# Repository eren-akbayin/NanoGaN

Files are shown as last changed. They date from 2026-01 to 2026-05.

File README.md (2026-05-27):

# NanoGaN

GaN-based motor driver using Infineon's latest GaN switches. Supports up to 60V (depending on GaN device selection).

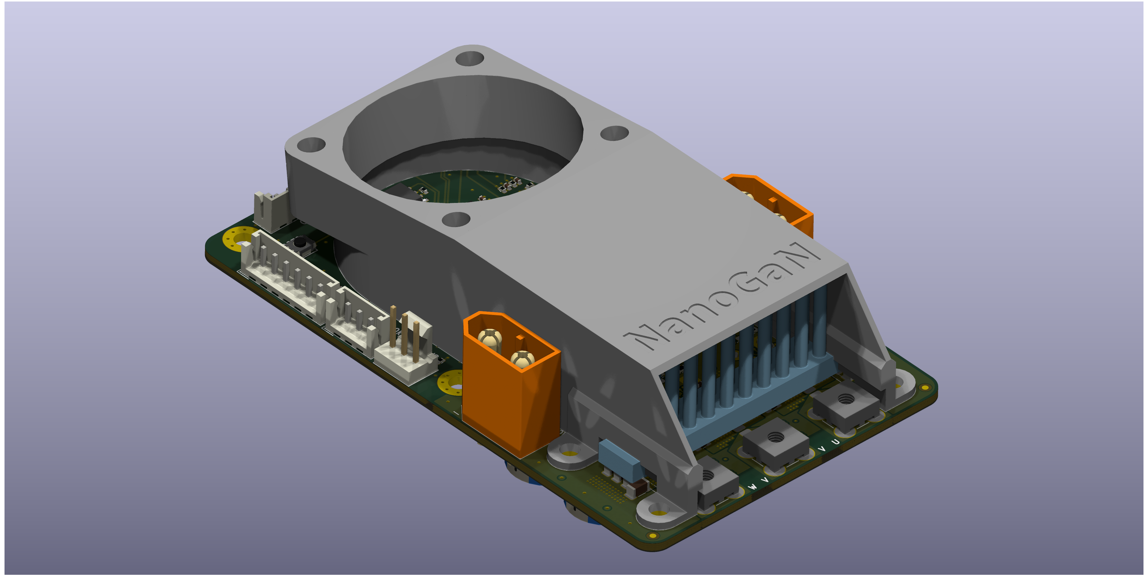
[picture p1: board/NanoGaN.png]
NanoGaN Board

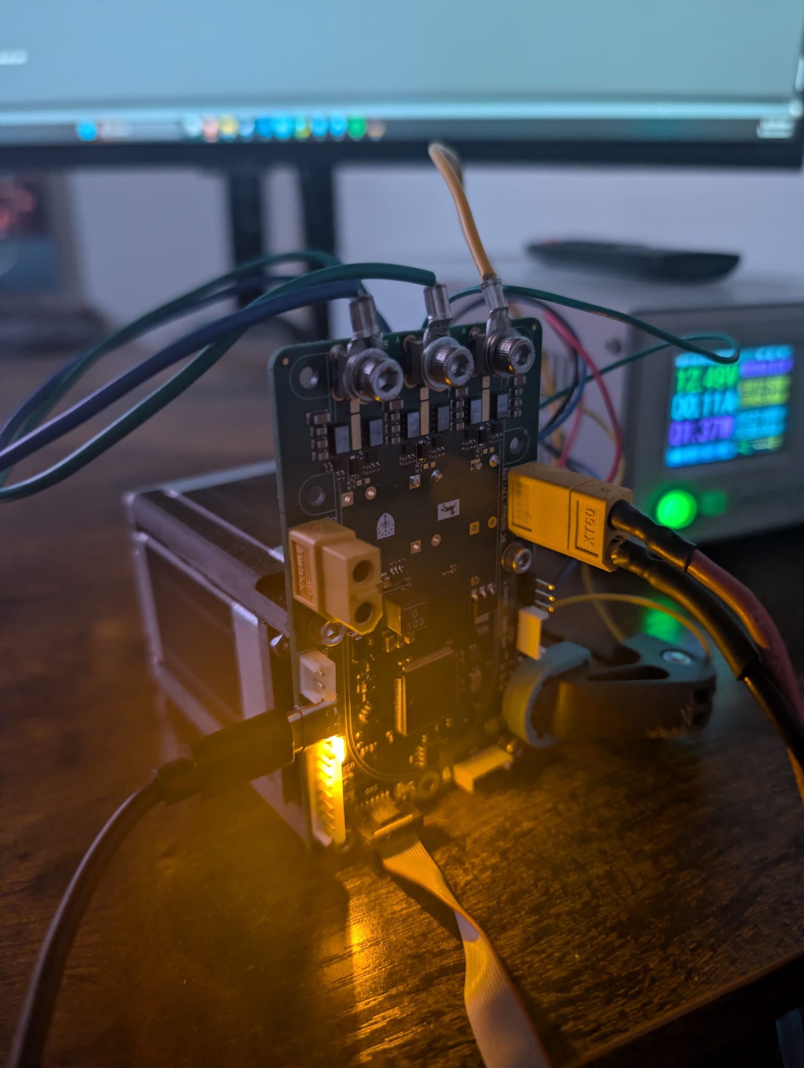
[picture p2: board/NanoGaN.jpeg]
NanoGaN Board


## Project Structure

- `NanoGaN.kicad_sch` - Main schematic file
- `NanoGaN.kicad_pcb` - PCB layout
- `half_bridge.kicad_sch` - Half bridge circuit schematic
- `power.kicad_sch` - Power supply schematic
- `mcu.kicad_sch` - Microcontroller schematic
- `connectors.kicad_sch` - Connector schematic

## Folders

- `board/` - 3D board render and PDF schematic
- `NanoGaN_3D_models/` - Component 3D models
- `NanoGaN.pretty/` - Custom footprints and symbols
- `production/` - BOM, netlist, and pick & place files
- `microcontroller/` - MCU configuration and interrupt table
- `documents/` - Additional documentation

## Building

Open `NanoGaN.kicad_pro` in KiCad to view the project. Main PCB file is `NanoGaN.kicad_pcb`.

## Interfaces

- ST-Link V3 MINIE (STDC14) - Debugging and reprogramming
- 10k NTC (x2)
- SPI/I2C/USART (mutually exclusive)
- Hall Sensor Connectors - Motor commutation feedback with filtering
- Fan Connector - Cooling fan control for 5V fans
- USB-C - Communication and configuration
- CAN Bus - Motor control and diagnostics
- Servo - Servo interface

## Production Files

Standard manufacturing outputs are in the `production/` folder:
- `bom.csv` - Bill of materials
- `positions.csv` - Pick and place coordinates
- `netlist.ipc` - IPC netlist
- `designators.csv` - Component designators

## Notes

GaN motor driver with Infineon GaN switches. Supports up to 60V depending on device selection. MCU is configured via `NanoGaN.ioc` (STM32CubeMX format).

## Example HF injection to 24V BLDC Motor
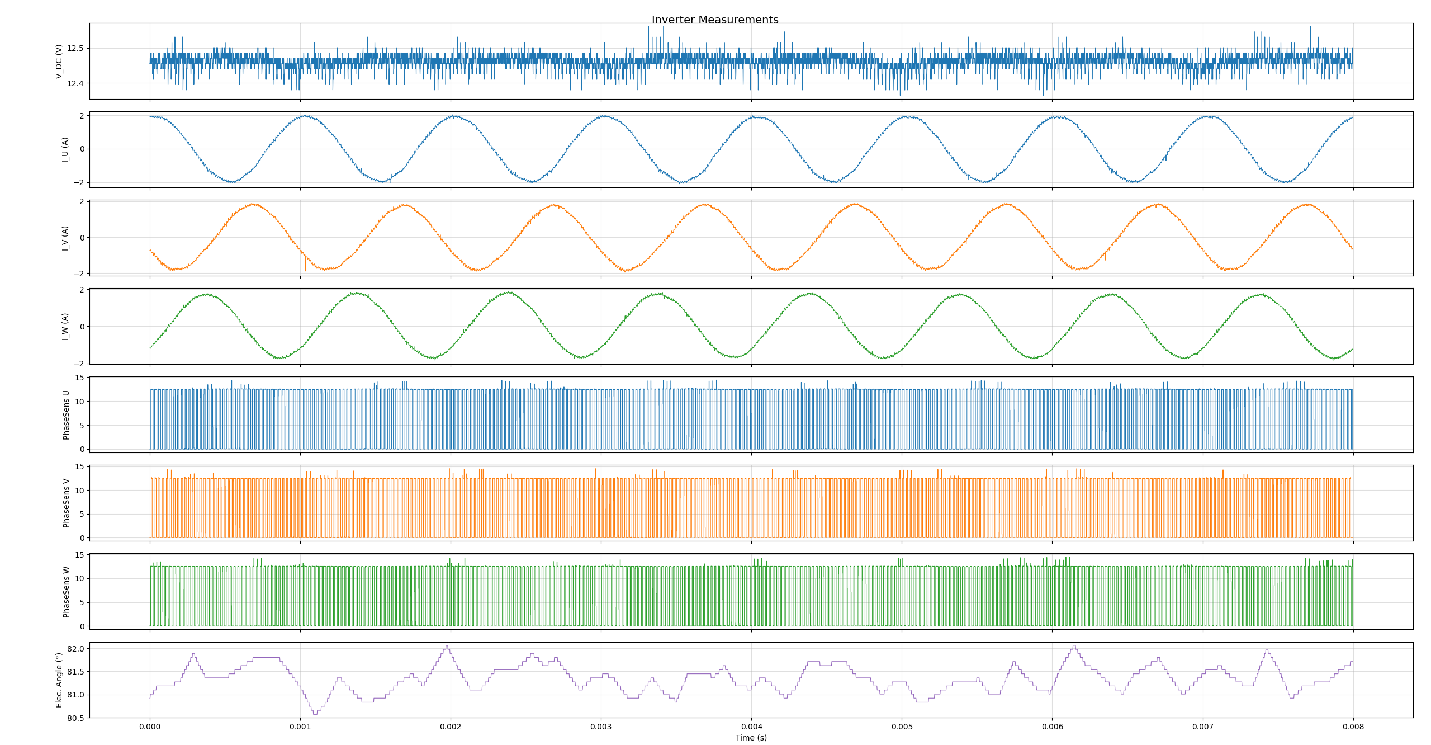
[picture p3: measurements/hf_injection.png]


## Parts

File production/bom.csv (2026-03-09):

Designator | Footprint | Quantity | Value | LCSC Part #
C1, C17, C2, C3, C42, C46, C68 | 1206 | 7 | CL31B105KCHNNNE | C13832
C10, C20, C29, C31, C43, C55, C56, C57, C64, C66, C72, C73, C74, C75, C76, C77, C78, C80, C96, C98 | 0402 | 20 | 0402B104K6R3CT | C424821
C11, C12, C13, C14, C27, C35 | CP_Radial_D12.5mm_P5.00mm | 6 | EKYC800ELL471MK25S
C15, C30, C32, C4, C44, C45, C47, C49, C50, C67, C81, C88, C90 | 0805 | 13 | CL21B104KCFNNNE | C28233
C16, C22, C23, C41, C48, C52, C53, C54, C63, C65, C9, C97 | 0402 | 12 | CL05B105KQ5NQNC | C307427
C19, C60, C61, C62, C94, C95 | 0402 | 6 | 0402B472K500NT | C1538
C24, C25, C26, C28, C33, C38, C39, C58, C59, C89, C91 | 0603 | 11 | ~
C37, C40, C7, C71, C79, C8, C93 | 0402 | 7 | CL05A475MP5NRNC | C23733
C5 | 0402 | 1 | CL05B104KO5NNNC | C1525
C6, C82, C86 | 1206 | 3 | CL31A476MPHNNNE | C96123
C69, C70 | 0402 | 2 | 0402CG330J500NT | C1549
C83, C84 | 0402 | 2 | CL05A225MQ5NSNC | C12530
CC1 | CoolingChannel | 1 | ~
D1, D6 | 0805 | 2 | YELLOW | C2296
D2 | SOT-23-6 | 1 | USBLC6-2SC6 | C7519
D3 | D_SMA | 1 | SS54 | C22452
D4 | 0805 | 1 | RED | C84256
D5 | 0805 | 1 | GREEN | C2297
D7, D8, D9 | D_SOD-123F | 3 | MBR2H200SFT1G | C480689
HS1 | ICK_S | 1 | Heatsink
J1, J2 | AMASS_XT60-M | 2 | XT60-M
J10 | JST_EH_B6B-EH-A_1x06_P2.50mm_Vertical | 1 | Conn_01x06
J11 | JST_EH_B4B-EH-A_1x04_P2.50mm_Vertical | 1 | Conn_01x04
J12 | USB_C_Receptacle_GCT_USB4105-xx-A_16P_TopMnt_Horizontal | 1 | USB_C_Receptacle_USB2.0_16P | C2988369
J14 | FanPinHeader_1x03_P2.54mm_Vertical | 1 | Conn_01x03
J3, J4, J5 | Wuerth_REDCUBE-THR_WP-THRBU_74650073_THR | 3 | Phase_U
J6 | FTSH10701LDVKTR | 1 | FTSH-107-01-L-DV-K-TR | C5307809
J7 | JST_EH_B3B-EH-A_1x03_P2.50mm_Vertical | 1 | Conn_01x03
J8 | JST_EH_B2B-EH-A_1x02_P2.50mm_Vertical | 1 | Conn_01x02
J9 | JST_EH_B7B-EH-A_1x07_P2.50mm_Vertical | 1 | Conn_01x07
L1 | IND_XAL60XX-240H_COC | 1 | XAL6060-103ME | C2911576
L2 | 0603 | 1 | FHW0603UC039JST | C295697
Q1, Q2, Q3, Q4, Q5, Q6 | IFX-PG-TSON-6-2-V | 6 | IGC025S08S1XTMA1 | C43313314
Q7 | SOT-23_3 | 1 | AO3400A | C20917
Q8 | SOT-23_3 | 1 | AO3400A
R1 | 0402 | 1 | 0402WGF1003TCE | C25741
R10, R20, R28, R4 | 0402 | 4 | NQ02WGF3902TCE | C965259
R11, R21, R34, R35, R36, R41, R42 | 0402 | 7 | 0402WGF1002TCE | C25744
R12, R26, R29, R30, R31, R33, R5, R56, R57 | 0402 | 9 | 0402WGF2201TCE | C25879
R15, R16, R22, R23, R44, R45, R46, R47, R48, R49, R8, R9 | 0402 | 12 | 0402WGF4702TCE | C25792
R19, R27, R32, R7 | 0402 | 4 | 0402WGF0000TCE | C17168
R2 | 0402 | 1 | 0402WGF1912TCE | C52036
R3, R43, R58, R59 | 0402 | 4 | 0402WGF2200TCE | C25091
R37, R38 | 0402 | 2 | 0402WGF5101TCE | C25905
R39 | 0402 | 1 | 0402WGF1000TCE | C25076
R40 | 0402 | 1 | 0402WGF1001TCE | C11702
R6 | 0402 | 1 | 0402WGF1200TCE | C25079
R60 | 0402 | 1 | 0402WGF5100TCE | C25123
SW1, SW2, SW3, SW4 | SW_TS-1088_XNP | 4 | TS-1088-AR02016 | C720477
U1 | LQFP-100_14x14mm_P0.5mm | 1 | STM32H723VGTx | C730142
U10, U11, U12, U13, U5, U8 | 1EDN71X6U | 6 | 1EDN7136U | C3654881
U14 | TSSOP-14_AMS-L | 1 | AS5047P-ATST | C962063
U15 | D0008A-MFG | 1 | TCAN1044VDRQ1 | C1852061
U2 | DDC0006A-MFG | 1 | LMR51635XDDCR | C42432812
U3 | SOT-223-3_TabPin2 | 1 | AMS1117 | C6186
U4, U6, U7 | ACS37030LLZATR020B3 | 3 | ACS37030LLZATR-065B3
U9 | LGA14-L_2P59X3P1X0P5_STM-L | 1 | LSM6DSVTR | C41785564
X1 | Crystal_SMD_3225-4Pin_3.2x2.5mm | 1 | X322512MSB4SI | C9002

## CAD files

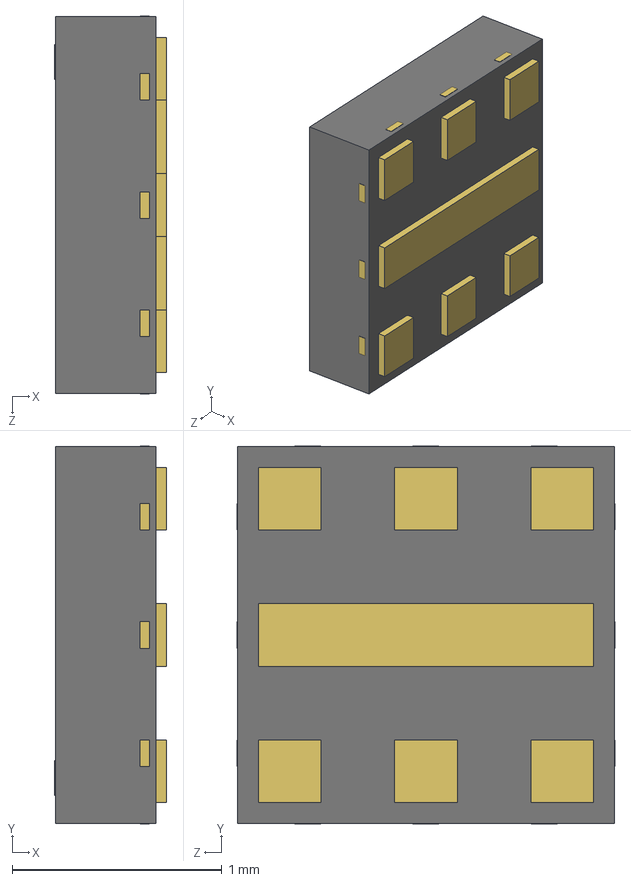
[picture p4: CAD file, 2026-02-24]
NanoGaN_3D_models/1EDN7136UXTSA1.stp
0.535 x 1.80 x 1.80 mm

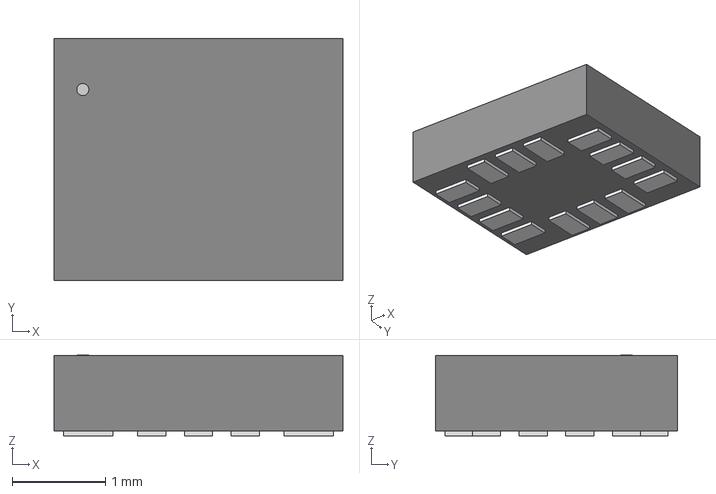
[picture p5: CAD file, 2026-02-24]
NanoGaN_3D_models/LGA14-L_2P59X3P1X0P5_STM.step
3.10 x 2.59 x 0.866 mm

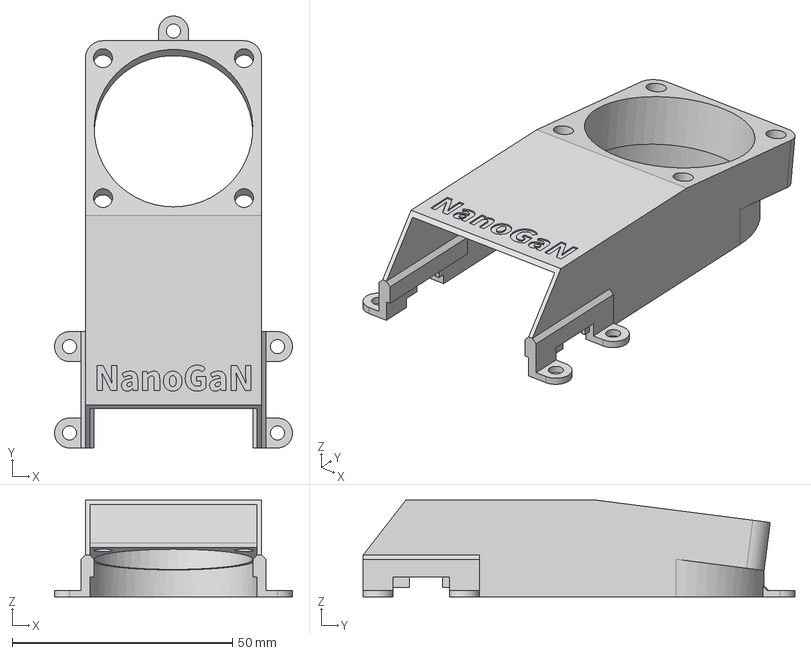
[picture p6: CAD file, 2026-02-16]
NanoGaN_3D_models/cc_v6.step
54.0 x 98.0 x 22.0 mm

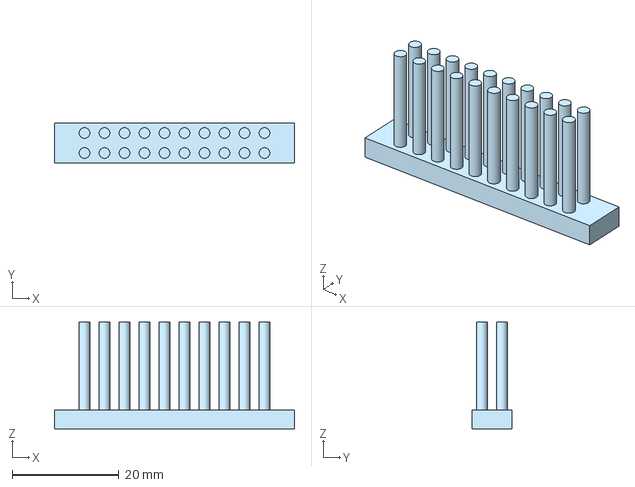
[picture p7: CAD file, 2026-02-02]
NanoGaN_3D_models/ICK_S.step
45.0 x 7.50 x 20.0 mm

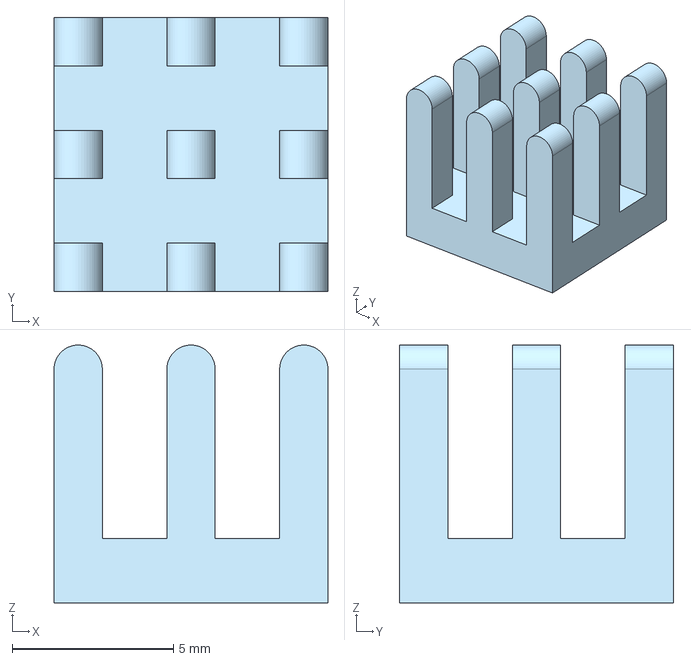
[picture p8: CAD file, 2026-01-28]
NanoGaN_3D_models/HSB01-080808.step
8.50 x 8.50 x 8.00 mm

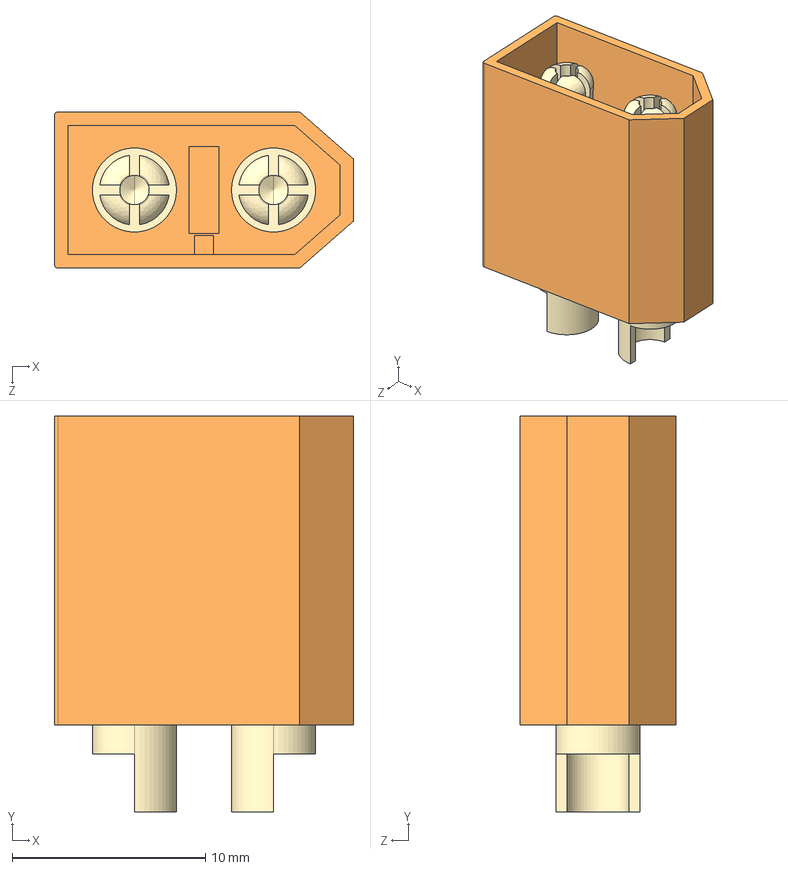
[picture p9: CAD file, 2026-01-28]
NanoGaN_3D_models/XT60-M--3DModel-STEP-510211.STEP
15.5 x 20.5 x 8.10 mm

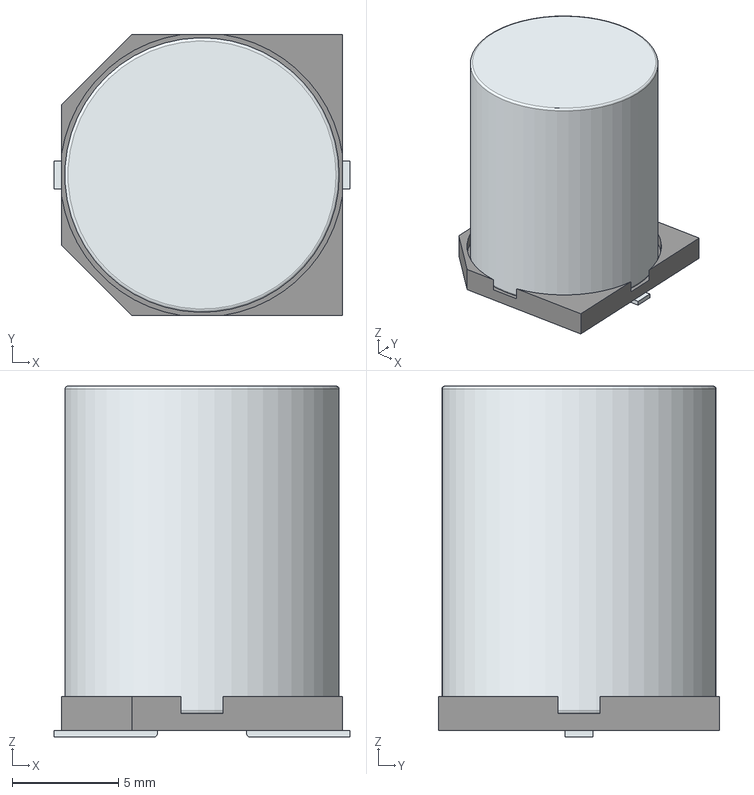
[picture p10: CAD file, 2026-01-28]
NanoGaN_3D_models/EMHS800GRA241MKG5S.stp
13.9 x 13.2 x 16.5 mm
Base
Pin1Fillet
Pin2Fillet

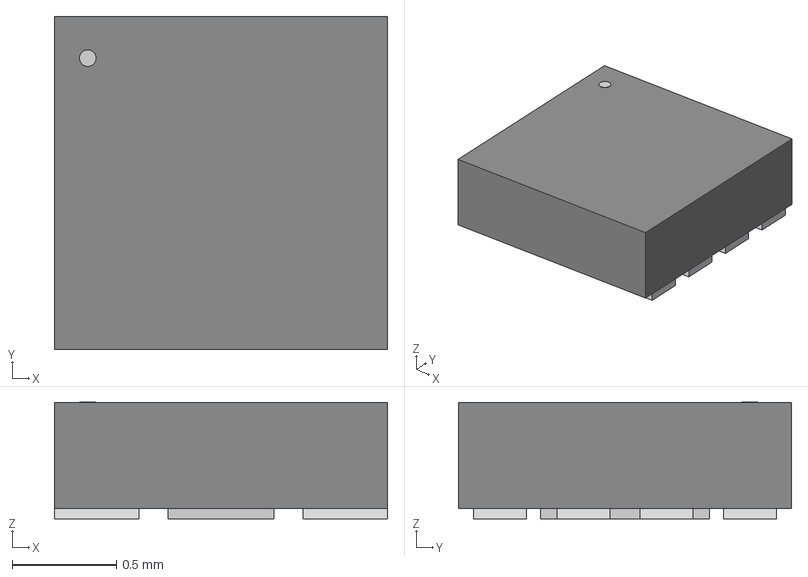
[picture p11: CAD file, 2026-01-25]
NanoGaN_3D_models/UDFN8_1P6X1P6_ONS.step
1.60 x 1.60 x 0.561 mm

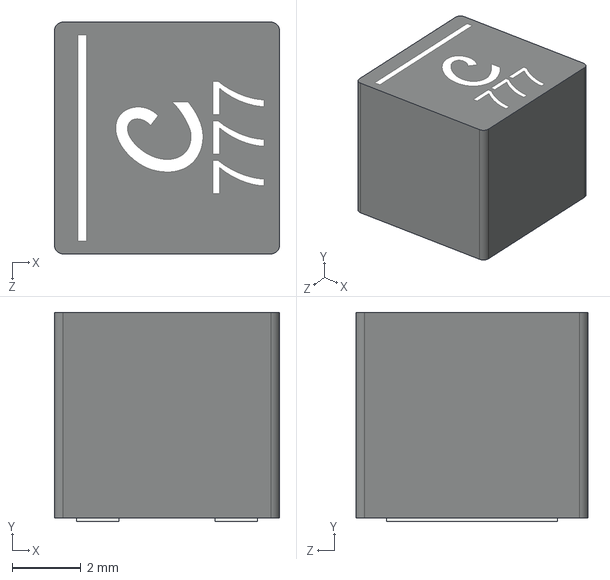
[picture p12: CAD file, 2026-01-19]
NanoGaN_3D_models/Coilcraft-XAL6060.step
6.56 x 6.10 x 6.76 mm

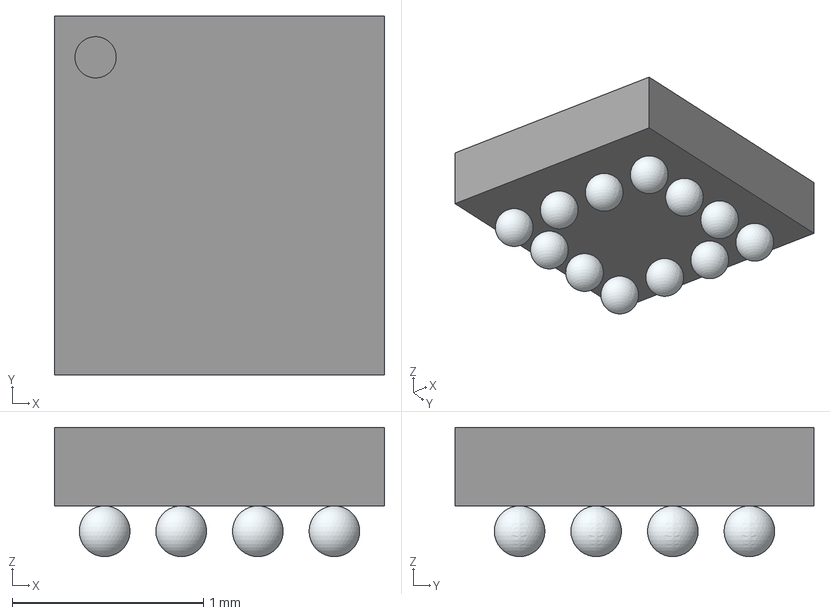
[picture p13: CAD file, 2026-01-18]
NanoGaN_3D_models/LMG1205YFXR.stp
1.73 x 1.88 x 0.675 mm
A1
A2
A3
A4
B1
B4
C1
C4
D1
D2
D3
D4

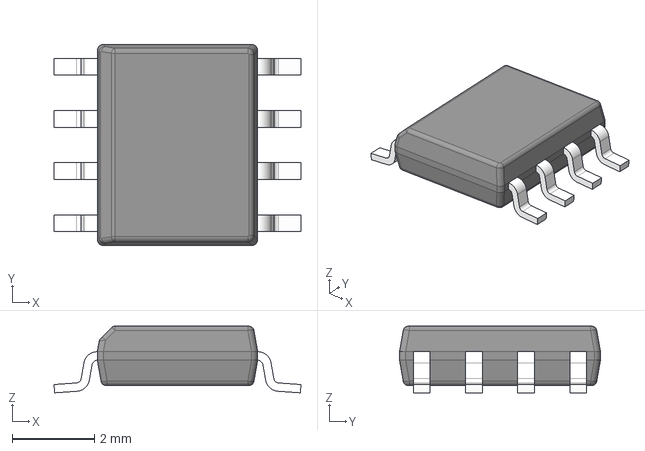
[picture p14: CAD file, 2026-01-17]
NanoGaN_3D_models/D0008A.stp
6.02 x 4.90 x 1.63 mm
BODY-SO
LEAD-D0008A x 8

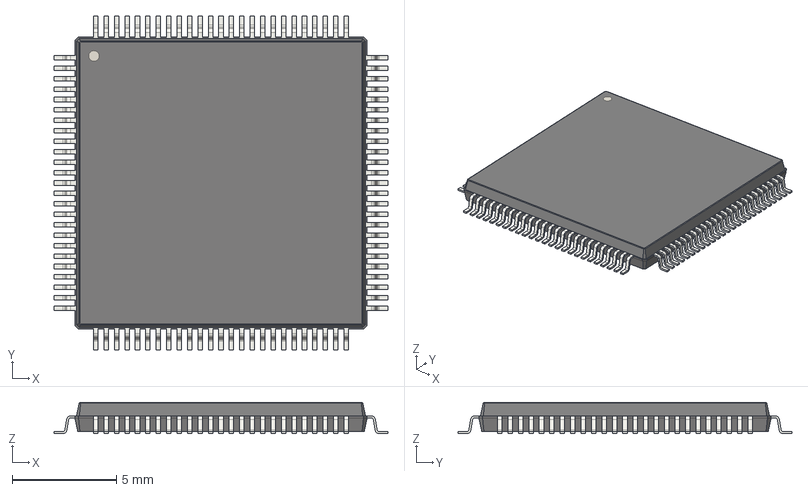
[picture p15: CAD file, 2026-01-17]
NanoGaN_3D_models/LQFP-100_14x14mm_P0.5mm.step
16.0 x 16.0 x 1.50 mm

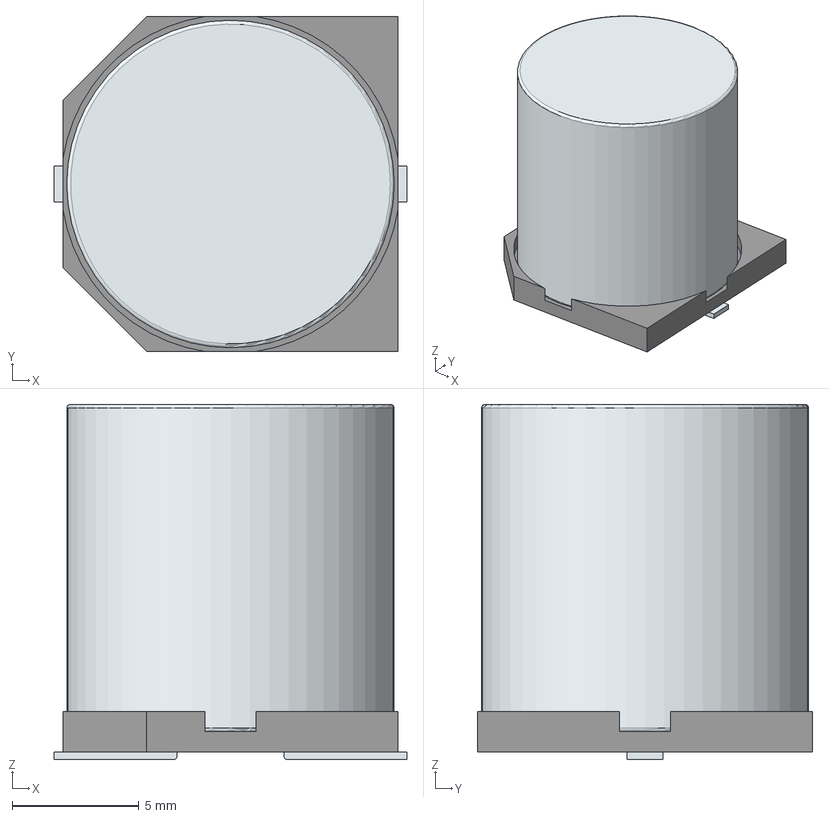
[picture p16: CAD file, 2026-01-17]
NanoGaN_3D_models/VZH221M1JTR-1313.stp
13.9 x 13.2 x 14.0 mm
Base
Pin1Fillet
Pin2Fillet

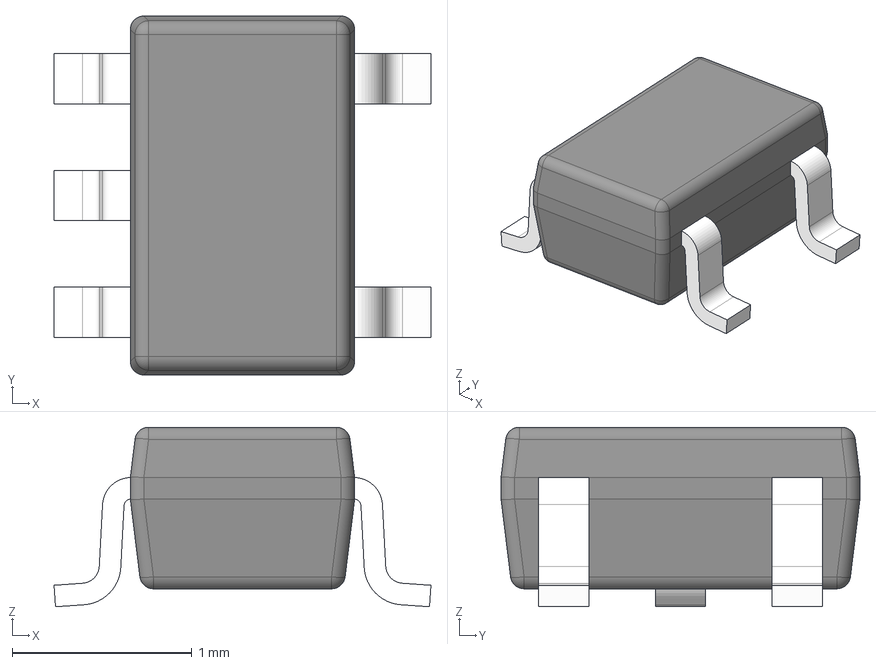
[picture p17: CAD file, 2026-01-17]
NanoGaN_3D_models/DCK0005A.stp
2.10 x 2.00 x 1.00 mm
BODY-SOT
LEAD-SOT x 5
PIN1-ID

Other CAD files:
NanoGaN_3D_models/DDC0006A.stp
NanoGaN_3D_models/RES_00FEA_VIS.step
NanoGaN_3D_models/PG-TSON-6-2_Z8B00184886_V04_3D.stp
NanoGaN_3D_models/FTSH-107-01-L-DV-K-TR.stp
NanoGaN_3D_models/ACS37030LLZATR-065B3.stp
NanoGaN_3D_models/TSSOP-14_AMS.step

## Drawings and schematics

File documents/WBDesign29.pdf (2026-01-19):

## WEBENCH ® Design Report

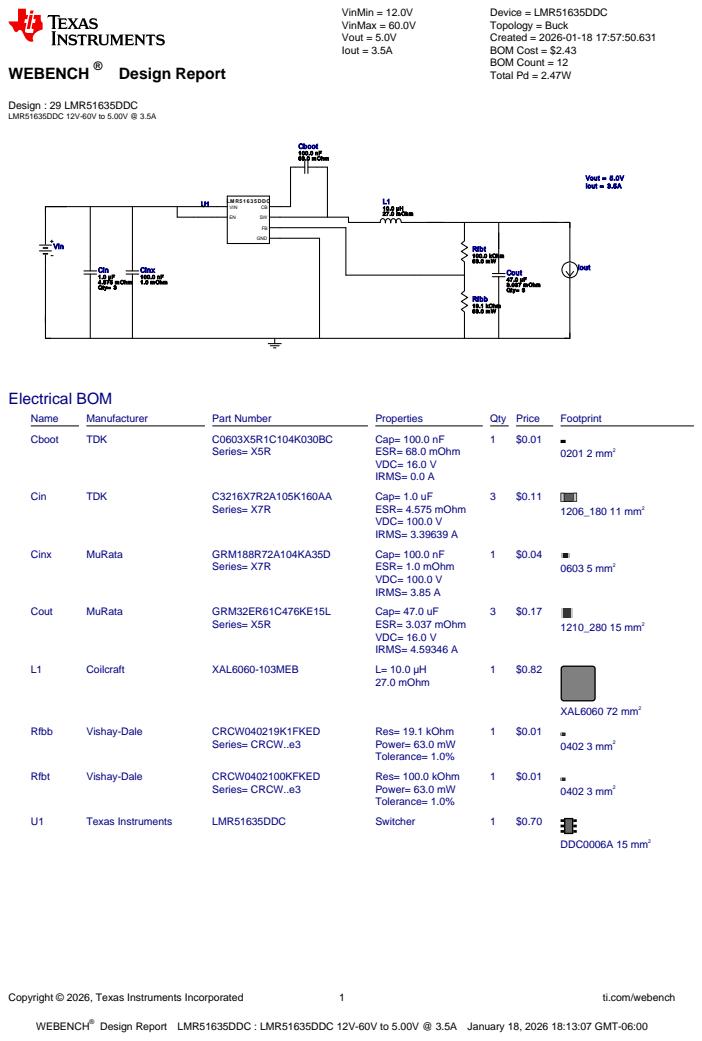
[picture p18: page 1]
Copyright © 2026, Texas Instruments Incorporated; ti.com/webench; WEBENCH®; Design : 29 LMR51635DDC LMR51635DDC 12V-60V to 5.00V @ 3.5A; VinMin = 12.0V VinMax = 60.0V Vout = 5.0V Iout = 3.5A; Device = LMR51635DDC Topology = Buck Created = 2026-01-18 17:57:50.631 BOM Cost = $2.43 BOM Count = 12 Total Pd = 2.47W; Cout 47.0 µF 3.037 m Ohm Qty= 3; Cinx 100.0 nF 1.0 m Ohm; L1 10.0 µH 27.0 m Ohm; LM R5 1 6 3 5 DDC; VIN; GND; Rfbb 19.1 kOhm 63.0 m W; Rfbt 100.0 kOhm 63.0 m W; Vout = 5.0V Iout = 3.5A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

Design Report LMR51635DDC : LMR51635DDC 12V-60V to 5.00V @ 3.5A January 18, 2026 18:13:07 GMT-06:00

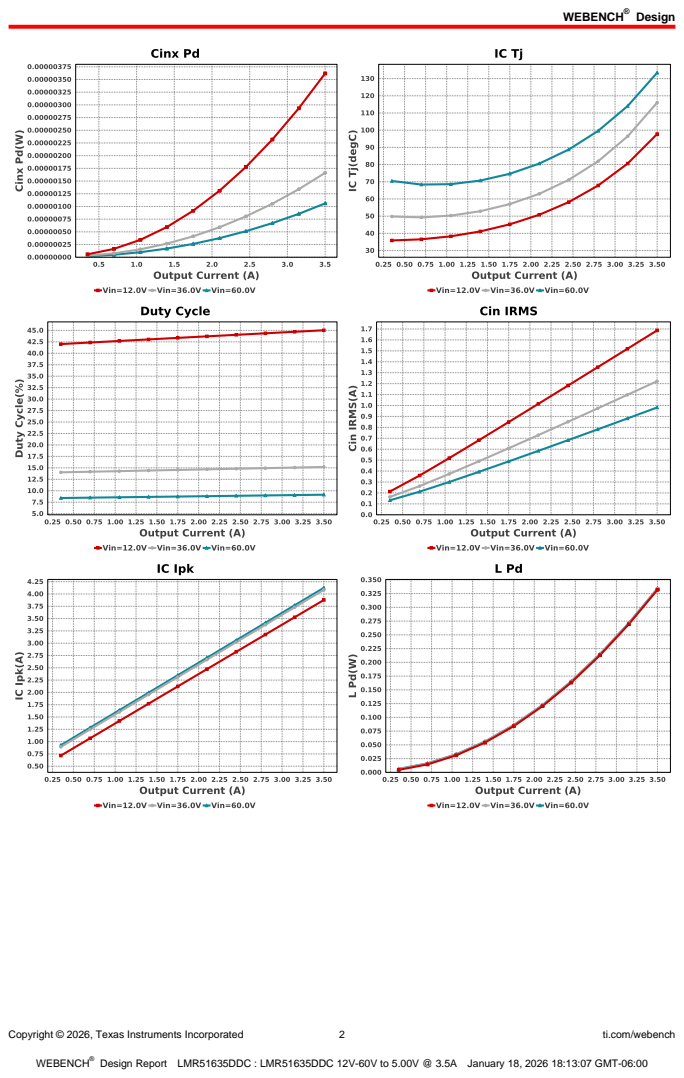
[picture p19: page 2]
Design; Copyright © 2026, Texas Instruments Incorporated; ti.com/webench

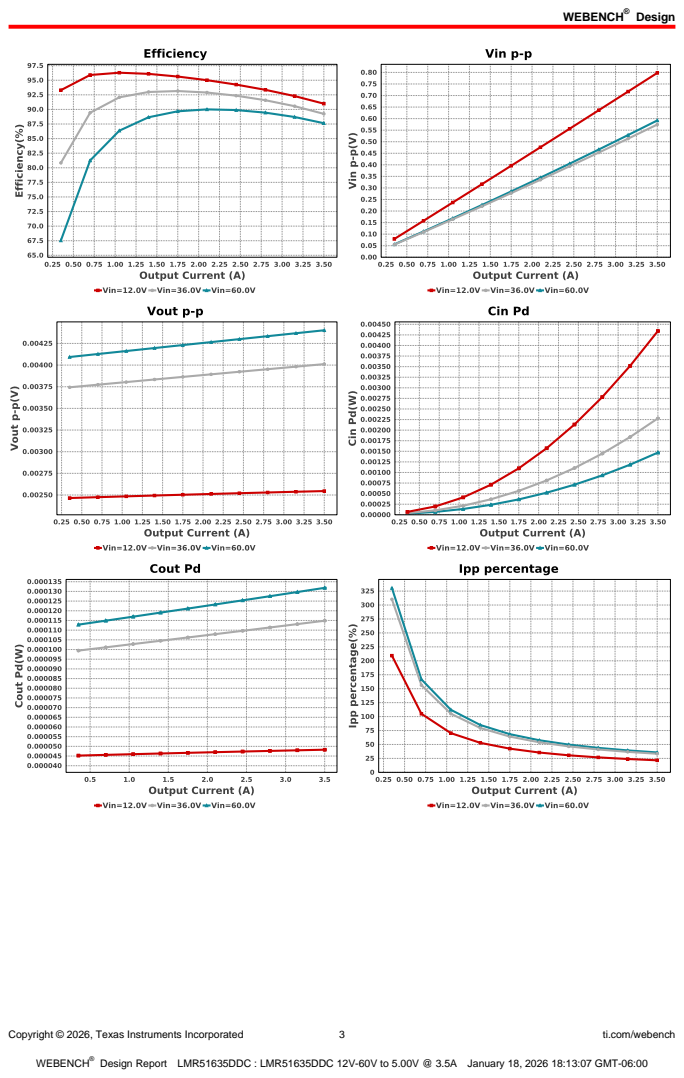
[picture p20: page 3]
Copyright © 2026, Texas Instruments Incorporated; ti.com/webench

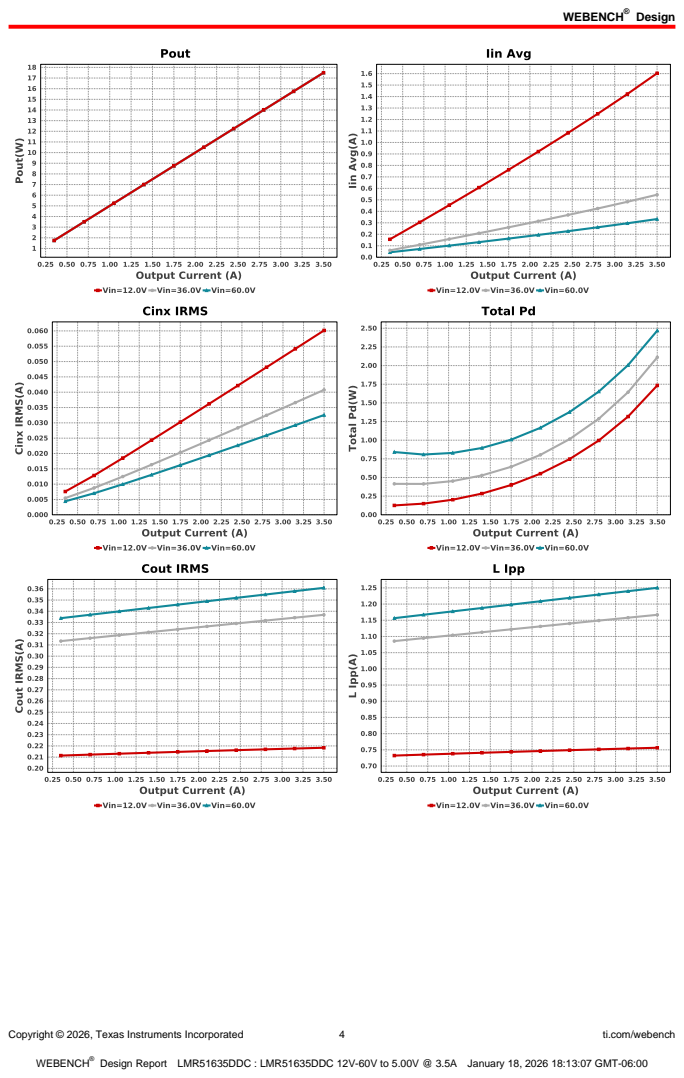
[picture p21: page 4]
Copyright © 2026, Texas Instruments Incorporated; ti.com/webench

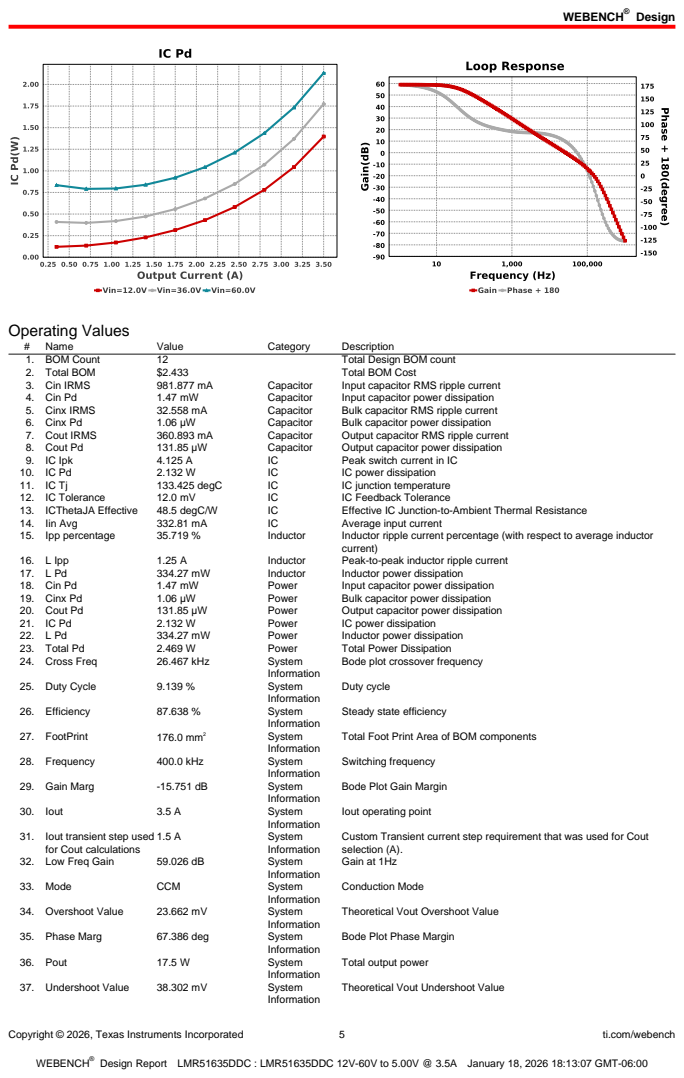
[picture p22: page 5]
Copyright © 2026, Texas Instruments Incorporated; ti.com/webench; Operating Values; Name; Value; Category; Description; 1. BOM Count; Total Design BOM count; 2. Total BOM; Total BOM Cost; 3. Cin IRMS; Capacitor; Input capacitor RMS ripple current; 4. Cin Pd; Input capacitor power dissipation; 5. Cinx IRMS; Bulk capacitor RMS ripple current; 6. Cinx Pd; Bulk capacitor power dissipation; 7. Cout IRMS; Output capacitor RMS ripple current; 8. Cout Pd; Output capacitor power dissipation; 9. IC Ipk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

Bode plot crossover frequency

Steady state efficiency

Total Foot Print Area of BOM components

Bode Plot Gain Margin

Iout operating point

31. Iout transient step used
for Cout calculations

Custom Transient current step requirement that was used for Cout
selection (A).
Gain at 1Hz

Theoretical Vout Overshoot Value

Bode Plot Phase Margin

Total output power

Theoretical Vout Undershoot Value

Copyright © 2026, Texas Instruments Incorporated | 6 | ti.com/webench
# | Name | Value | Category | Description

38. Vin | 60.0 V | System
| | | Information | Vin operating point
39. Vin p-p | 592.118 mV | System
| | | Information | Peak-to-peak input voltage
40. Vout | 5.0 V | System
| | | Information | Operational Output Voltage
41. Vout Actual | 4.988 V | System
| | | Information | Vout Actual calculated based on selected voltage divider resistors
42. Vout Ripple
| requirement used for Cout calculations | 3.0 % | System Information | Custom maximum output ripple requirement that was used for Cout selection(% of Vout).
43. Vout Tolerance | 3.222 % | System
| | | Information | Vout Tolerance based on IC Tolerance (no load) and voltage divider resistors if applicable
44. Vout p-p | 4.402 mV | System
| | | Information | Peak-to-peak output ripple voltage
45. Vout transient
| requirement used for Cout calculations | 3.0 % | System Information | Custom Transient voltage change requirement that was used for Cout selection (% of Vout).

## Design Inputs

Name | Value | Description
Iout | 3.5 | Maximum Output Current
VinMax | 60.0 | Maximum input voltage
VinMin | 12.0 | Minimum input voltage
Vout | 5.0 | Output Voltage
| base_pn | | LMR51635 | Base Product Number
source | DC | Input Source Type
Ta | 30.0 | Ambient temperature


Copyright © 2026, Texas Instruments Incorporated | 7 | ti.com/webench

## Assembly

## Component Testing

Some published data on components in datasheets such as Capacitor ESR and Inductor DC resistance is based on conservative values that will guarantee that the components always exceed the specification. For design purposes it is usually better to work with typical values. Since this data is not always available it is a good practice to measure the Capacitance and ESR values of Cin and Cout, and the inductance and DC resistance of L1 before assembly of the board. Any large discrepancies in values should be electrically simulated in WEBENCH to check for instabilities and thermally simulated in WebTHERM to make sure critical temperatures are not exceeded.
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

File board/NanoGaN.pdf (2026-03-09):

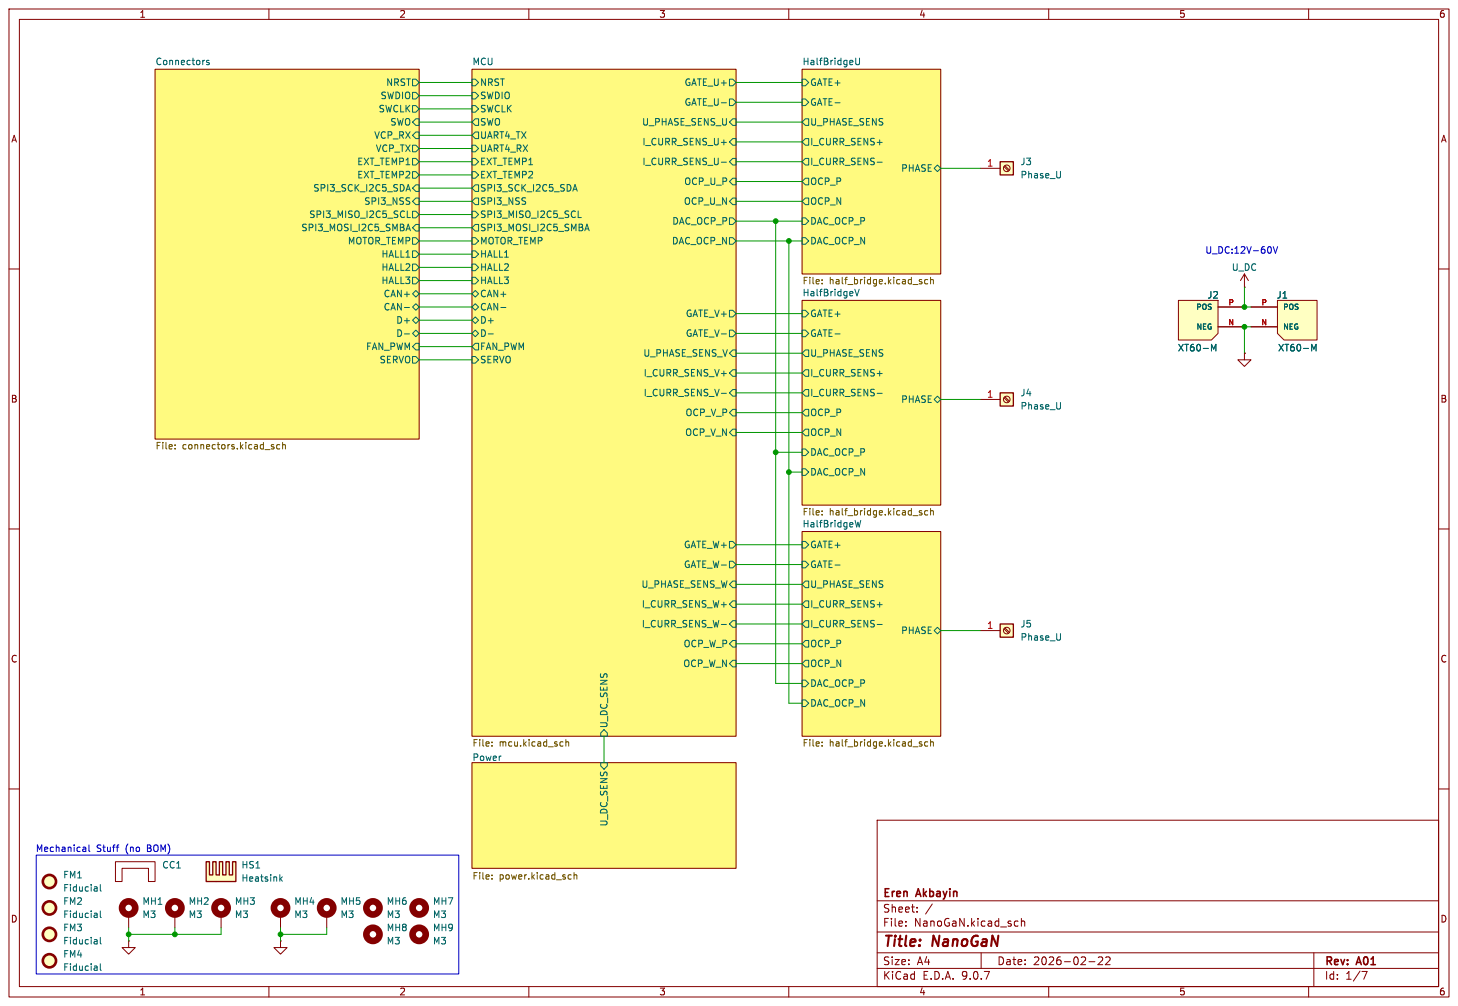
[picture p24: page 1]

File: NanoGaN.kicad_sch Sheet: / Eren Akbayin

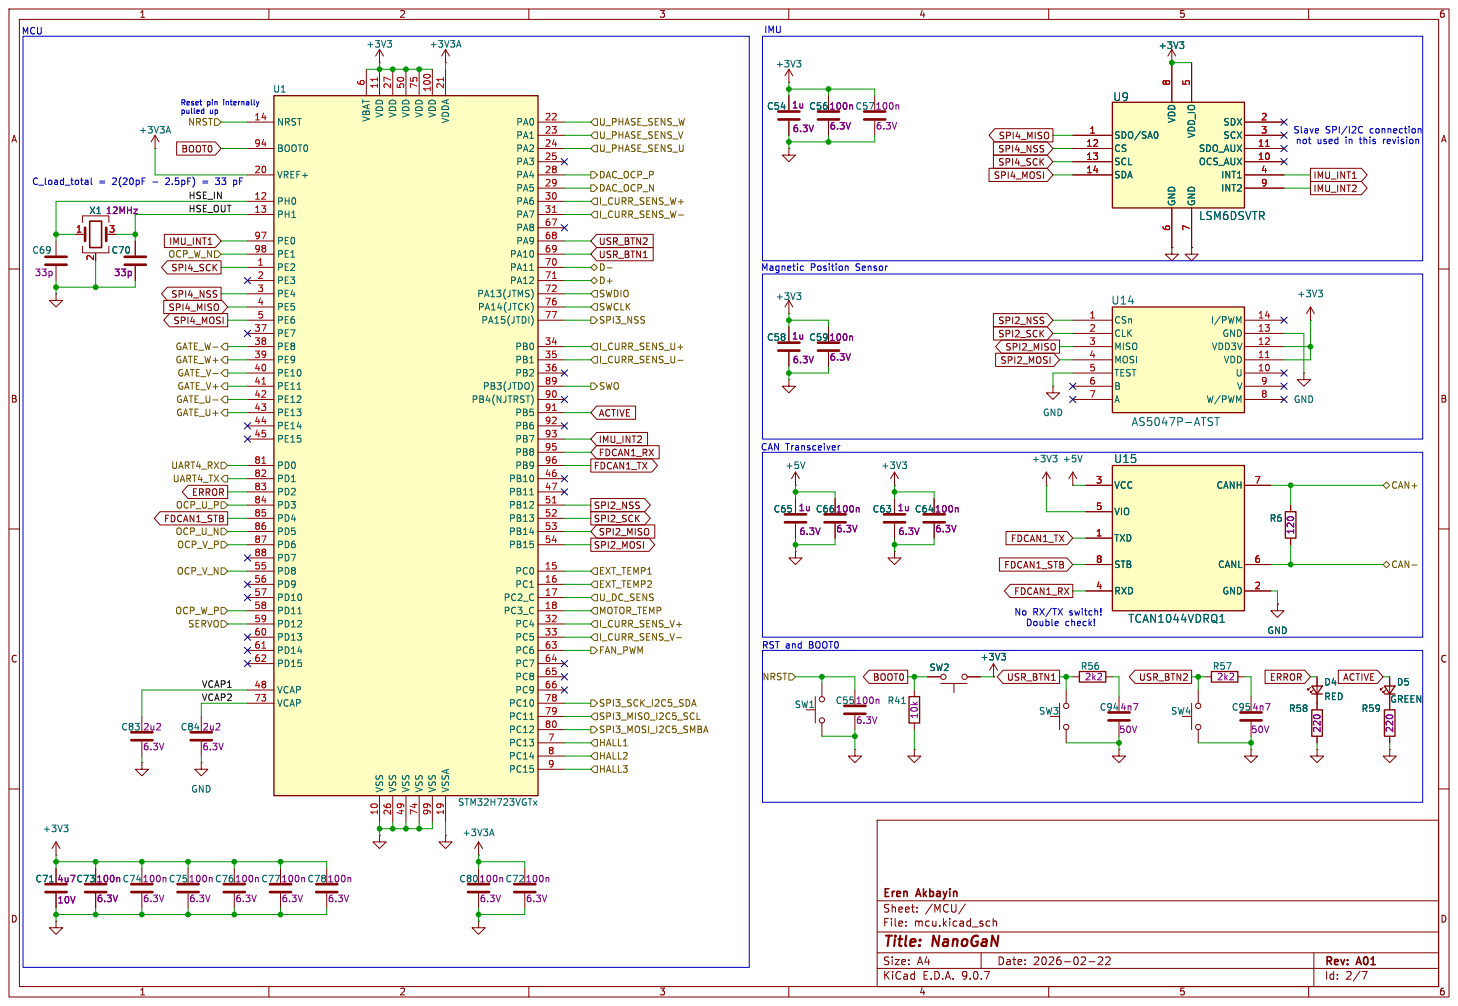
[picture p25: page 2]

not used in this revision GND

6 VDD 11 VSS 10 VDD 27 VSS 26 VDD 50 VSS 49 VDD 75 VSS 74 VDD 100 VSS 99 VDDA 21 VSSA 19 PA0 22 PA1 23 PA2 24 PA3 25 PA4 28 PA5 29 PA6 30 PA7 31 PA8 67 PA9 68 PA10 69 PA11 70 PA12 71 PA13(JTMS) 72 PA14(JTCK) 76 PA15(JTDI) 77 PB0 34 PB1 35 PB2 36 PB3(JTDO) 89 PB4(NJTRST) 90 PB5 91 PB6 92 PB7 93 PB8 95 PB9 96 PB10 46 PB11 47 PB12 51 PB13 52 PB14 53 PB15 54 PC0 15 PC1 16 PC2_C 17 PC3_C 18 PC4 32 PC5 33 PC6 63 PC7 64 PC8 65 PC9 66 PC10 78 PC11 79 PC12 80 PC13 7 PC14 8 PC15 9

File: mcu.kicad_sch Sheet: /MCU/ Eren Akbayin

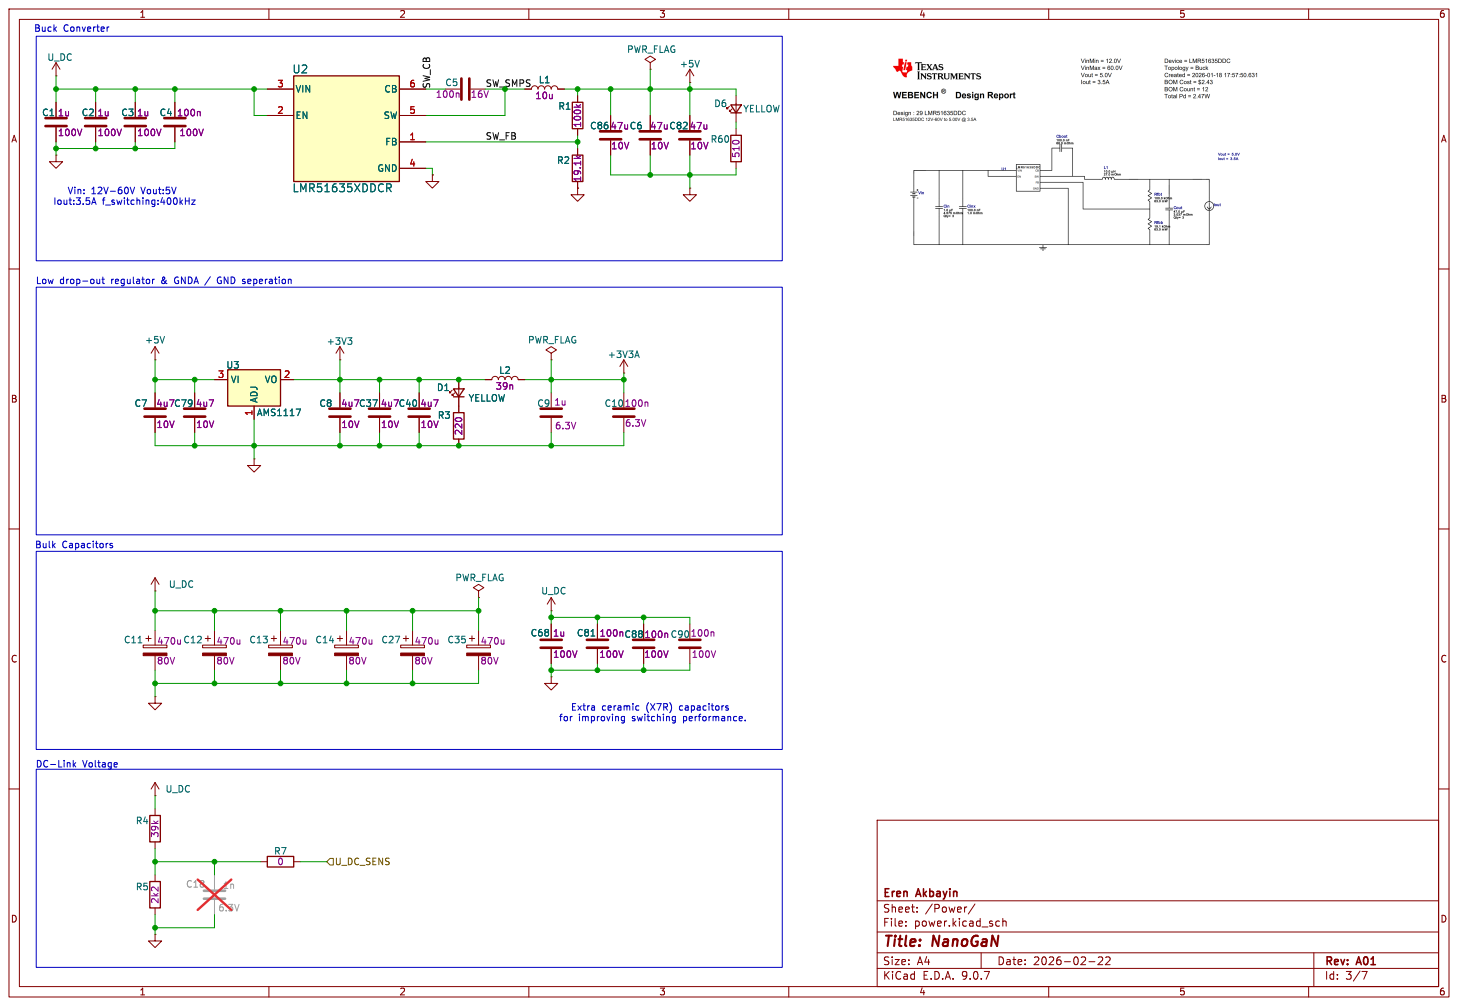
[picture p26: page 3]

File: power.kicad_sch Sheet: /Power/ Eren Akbayin C88 100n

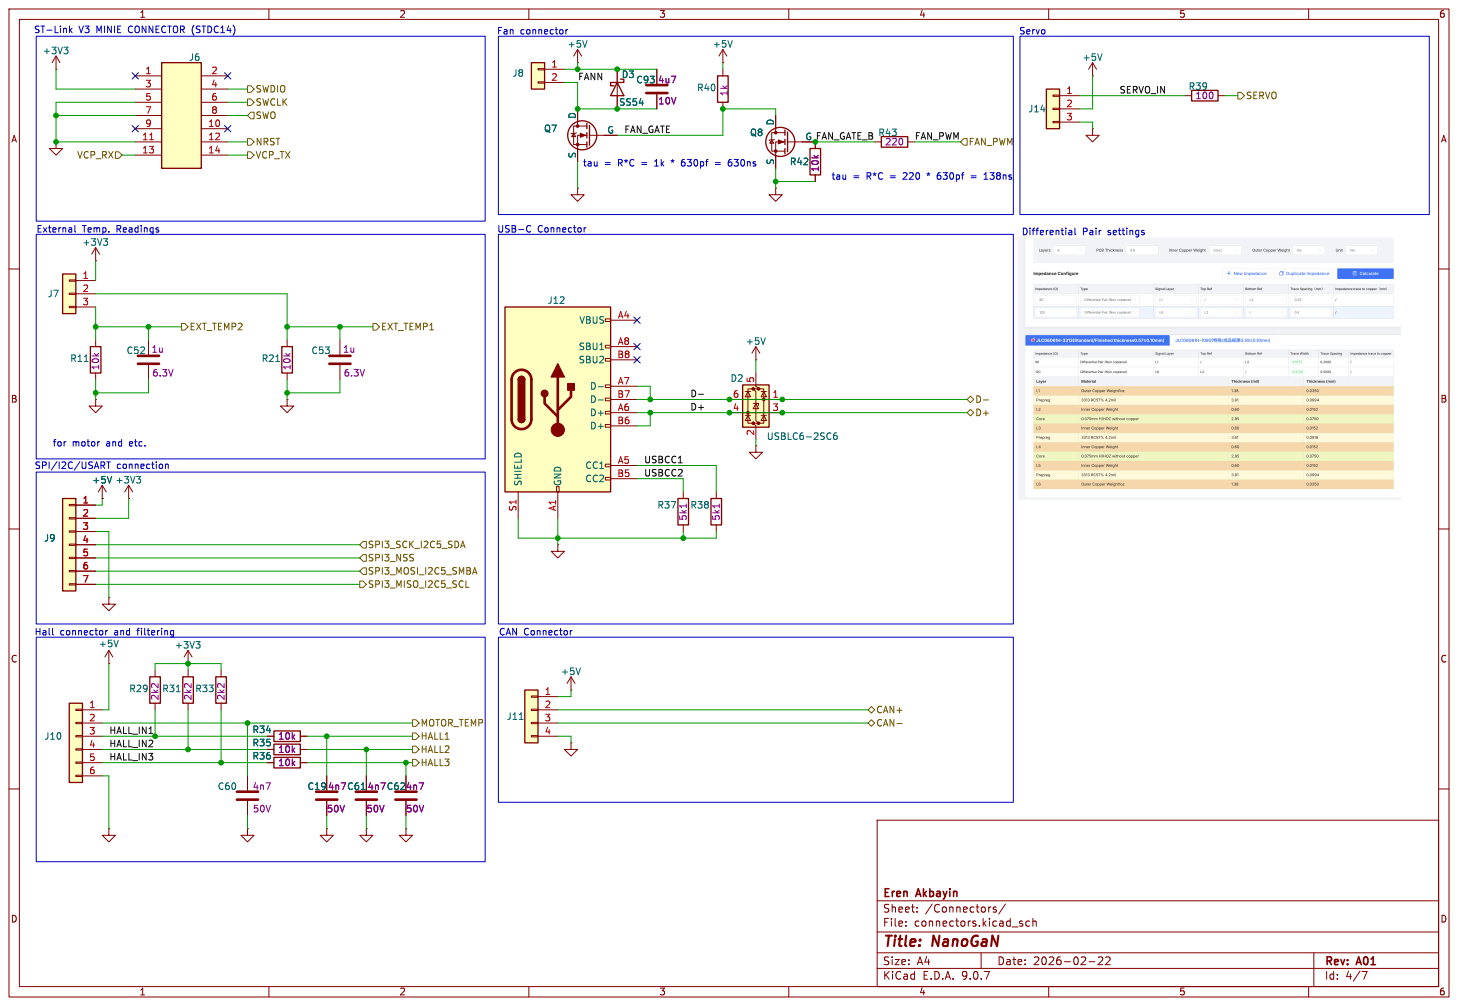
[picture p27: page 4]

File: connectors.kicad_sch Sheet: /Connectors/ Eren Akbayin

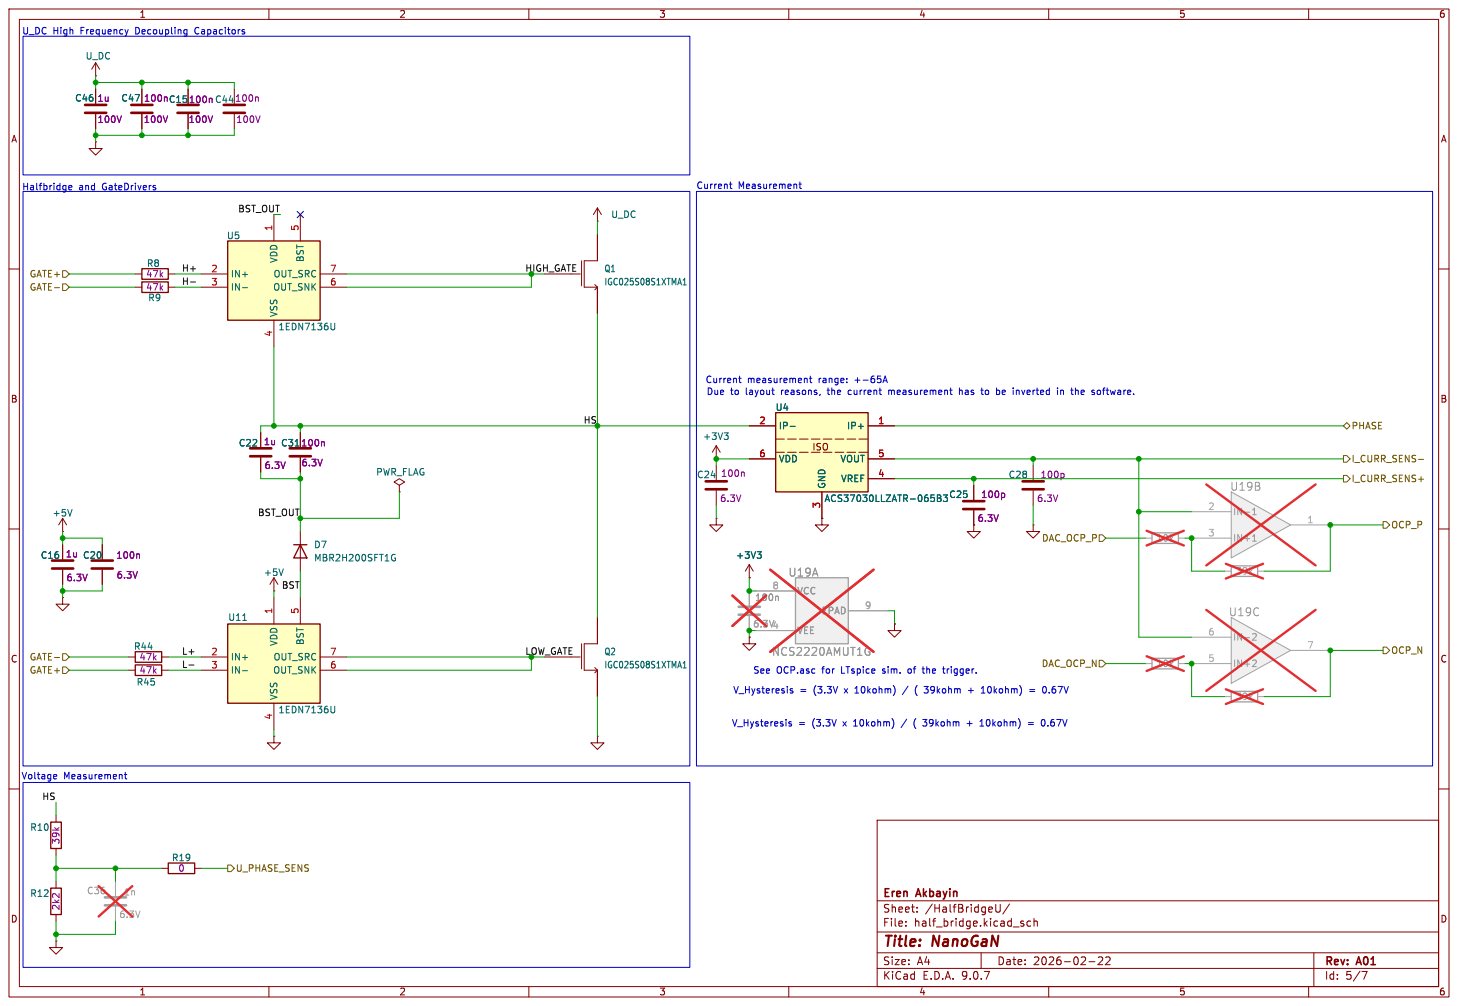
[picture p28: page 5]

See OCP.asc for LTspice sim. of the trigger.

File: half_bridge.kicad_sch Sheet: /HalfBridgeU/ Eren Akbayin

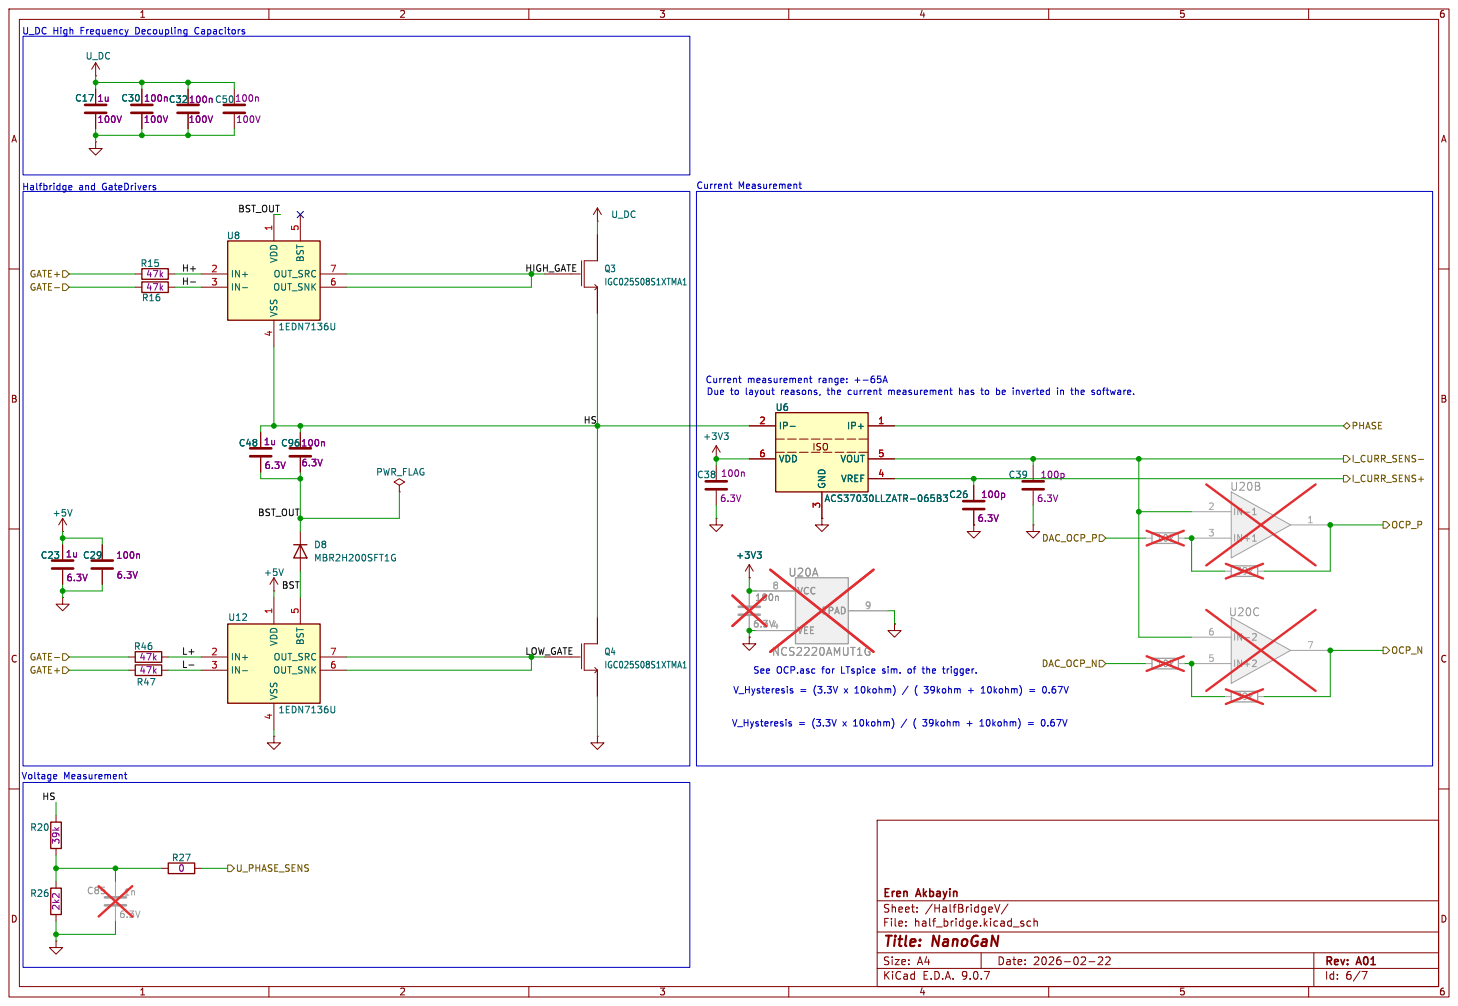
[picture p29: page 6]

See OCP.asc for LTspice sim. of the trigger.

File: half_bridge.kicad_sch Sheet: /HalfBridgeV/ Eren Akbayin


See OCP.asc for LTspice sim. of the trigger.

File: half_bridge.kicad_sch Sheet: /HalfBridgeW/ Eren Akbayin

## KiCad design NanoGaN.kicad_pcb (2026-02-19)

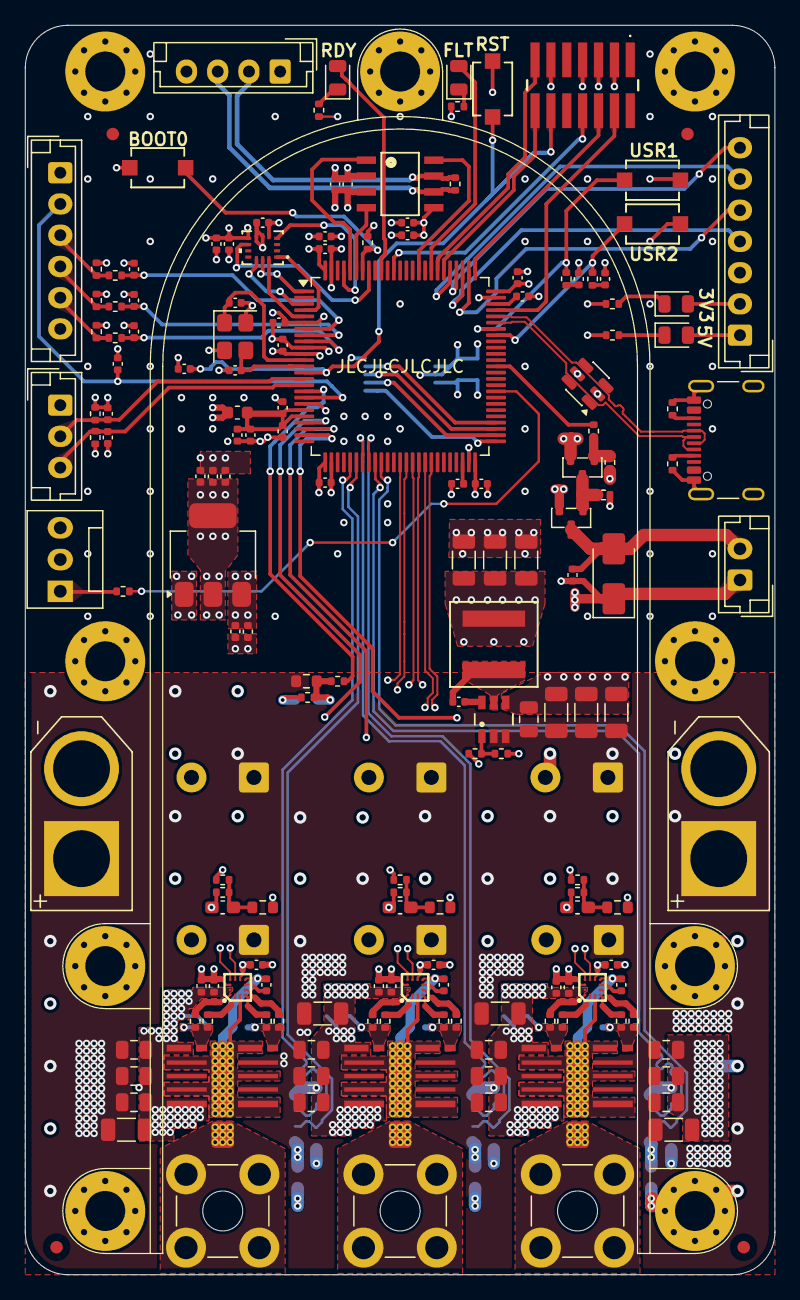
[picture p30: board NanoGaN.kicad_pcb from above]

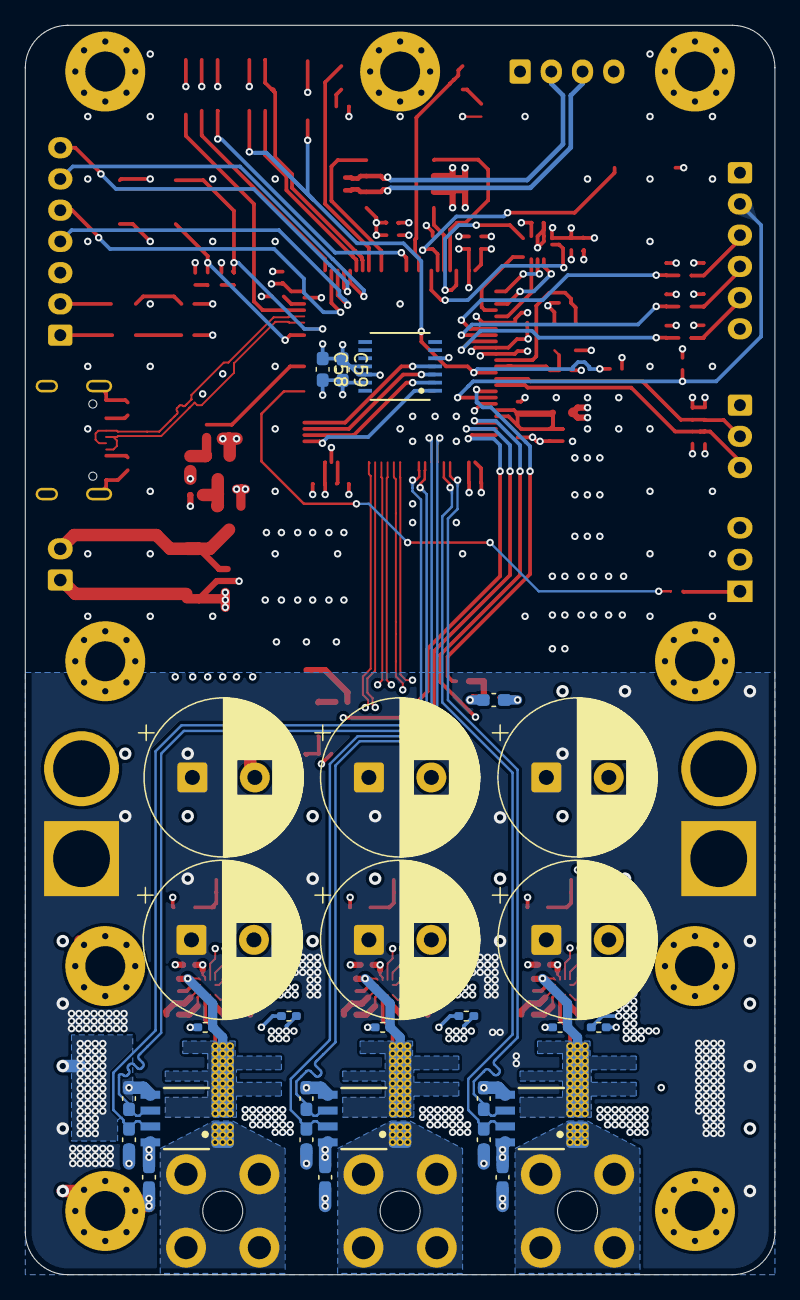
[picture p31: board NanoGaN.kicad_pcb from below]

Board: 6 copper layers, 60.0 x 100.0 mm, 212 parts (28 on the bottom side), 114 nets.

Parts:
C1, C2, C3, C17, C42, C46, C68: CL31B105KCHNNNE; C_1206_3216Metric
C4, C15, C30, C32, C44, C45, C47, C49, C50, C67, C81, C88, C90: CL21B104KCFNNNE; C_0805_2012Metric
C5: CL05B104KO5NNNC; C_0402_1005Metric
C6, C82, C86: CL31A476MPHNNNE; C_1206_3216Metric
C7, C8, C37, C40, C71, C79, C93: CL05A475MP5NRNC; C_0402_1005Metric
C9, C16, C23, C41, C52, C53, C54, C63, C65: CL05B105KQ5NQNC; C_0402_1005Metric
C10, C20, C21, C22, C29, C31, C34, C43, C48, C51, C55, C56, C57, C64, C66, C72, C73, C74, C75, C76, C77, C78, C80: 0402B104K6R3CT; C_0402_1005Metric
C11, C12, C13, C14, C27, C35: EKYC800ELL471MK25S; CP_Radial_D12.5mm_P5.00mm
C18, C24, C25, C26, C28, C33, C36, C38, C39, C58, C59, C85, C87, C89, C91: C_0603_1608Metric_Pad1.08x0.95mm_HandSolder
C19, C60, C61, C62, C94, C95: 0402B472K500NT; C_0402_1005Metric
C69, C70: 0402CG330J500NT; C_0402_1005Metric
C83, C84: CL05A225MQ5NSNC; C_0402_1005Metric
CC1: CoolingChannel
D1, D6: YELLOW; LED_0805_2012Metric
D2: USBLC6-2SC6; SOT-23-6
D3: SS54; D_SMA
D4: RED; LED_0805_2012Metric
D5: GREEN; LED_0805_2012Metric
FM1, FM2, FM3, FM4: Fiducial; Fiducial_1mm_Mask2mm
HB_PAD_U: HB_PAD
HS1: Heatsink; ICK_S
J1, J2: XT60-M; AMASS_XT60-M
J3: Phase_U; Wuerth_REDCUBE-THR_WP-THRBU_74650073_THR
J4: Phase_V; Wuerth_REDCUBE-THR_WP-THRBU_74650073_THR
J5: Phase_W; Wuerth_REDCUBE-THR_WP-THRBU_74650073_THR
J6: FTSH-107-01-L-DV-K-TR; FTSH10701LDVKTR
J7: Conn_01x03; JST_EH_B3B-EH-A_1x03_P2.50mm_Vertical
J8: Conn_01x02; JST_EH_B2B-EH-A_1x02_P2.50mm_Vertical
J9: Conn_01x07; JST_EH_B7B-EH-A_1x07_P2.50mm_Vertical
J10: Conn_01x06; JST_EH_B6B-EH-A_1x06_P2.50mm_Vertical
J11: Conn_01x04; JST_EH_B4B-EH-A_1x04_P2.50mm_Vertical
J12: USB_C_Receptacle_USB2.0_16P; USB_C_Receptacle_GCT_USB4105-xx-A_16P_TopMnt_Horizontal
J14: Conn_01x03; FanPinHeader_1x03_P2.54mm_Vertical
L1: XAL6060-103ME; IND_XAL60XX-240H_COC
L2: FHW0603UC039JST; L_0603_1608Metric
MH1, MH2, MH3, MH4, MH5, MH6, MH7, MH8, MH9: M3; MountingHole_3.2mm_M3_Pad_Via
Q1, Q2, Q3, Q4, Q5, Q6: IGC019S06S1XTMA1; IFX-PG-TSON-6-2-V
Q7, Q8: AO3400A; SOT-23_3
R1: 0402WGF1003TCE; R_0402_1005Metric
R2: 0402WGF1912TCE; R_0402_1005Metric
R3, R43, R58, R59, R60: 0402WGF2200TCE; R_0402_1005Metric
R4, R10, R20, R28: 0603WAF3902T5E; R_0603_1608Metric
R5, R12, R26, R30: 0402WGF2201TCE; R_0402_1005Metric
R6: 0402WGF1200TCE; R_0402_1005Metric
R7, R19, R27, R32: 0402WGF0000TCE; R_0402_1005Metric
R8, R9, R15, R16, R22, R23: CRCW04021R00FKEDHP; R_0402_1005Metric
R11, R21, R34, R35, R36, R41, R42: 0402WGF1002TCE; R_0402_1005Metric
R13, R14, R17, R18, R24, R25: R_0402_1005Metric_Pad0.72x0.64mm_HandSolder
R29, R31, R33, R40, R56, R57: 0402WGF1001TCE; R_0402_1005Metric
R37, R38: 0402WGF5101TCE; R_0402_1005Metric
R39: 0402WGF1000TCE; R_0402_1005Metric
R44, R45, R46, R47, R48, R49: CSR0402FKR500; R_0402_1005Metric
SW1, SW2, SW3, SW4: TS-1088-AR02016; SW_TS-1088_XNP
U1: STM32H723VGTx; LQFP-100_14x14mm_P0.5mm
U2: LMR51635XDDCR; DDC0006A-MFG
U3: AMS1117; SOT-223-3_TabPin2
U4, U6, U7: ACS37030LLZATR-065B3; ACS37030LLZATR020B3
U5, U8, U12: LMG1205YFXR; BGA12C40P4X4_173X188X68
U13: BMI323; BMI323_BOS
U14: AS5047P-ATST; TSSOP-14_AMS-L
U15: TCAN1044VDRQ1; D0008A-MFG
U_HB_PAD: HB_PAD
V_HB_PAD: HB_PAD
X1: X322512MSB4SI; Crystal_SMD_3225-4Pin_3.2x2.5mm

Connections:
+3V3: C8.1, C24.1, C37.1, C38.1, C40.1, C54.1, C56.1, C57.1, C58.1, C59.1, C63.1, C64.1, C71.1, C73.1, C74.1, C75.1, C76.1, C77.1, C78.1, C89.1, D1.2 (A), J6.3, J7.1, J9.2, L2.1, R29.1, R31.1, R33.1, SW2.1, U1.6 (VBAT), U1.11 (VDD), U1.27 (VDD), U1.50 (VDD), U1.75 (VDD), U1.100 (VDD), U3.2 (VO), U4.6 (VDD), U6.6 (VDD), U7.6 (VDD), U13.5 (VDDIO), U13.8 (VDD), U14.11 (VDD), U14.12 (VDD3V), U15.5 (VIO)
+3V3A: C9.1, C10.1, C72.1, C80.1, L2.2, U1.20 (VREF+), U1.21 (VDDA)
+5V: C6.1, C7.1, C16.1, C20.1, C22.1, C23.1, C29.1, C31.1, C41.1, C43.1, C48.1, C65.1, C66.1, C79.1, C82.1, C86.1, C93.1, D2.5 (VBUS), D3.1 (K), D6.2 (A), J8.1, J9.1, J10.1, J11.1, J14.2, L1.2, R1.1, R40.1, U3.3 (VI), U5.A3 (VDD), U5.C4 (VDD), U8.A3 (VDD), U8.C4 (VDD), U12.A3 (VDD), U12.C4 (VDD), U15.3 (VCC)
/Connectors/CAN+: J11.2, R6.1, U15.7 (CANH)
/Connectors/CAN-: J11.3, R6.2, U15.6 (CANL)
/Connectors/D+: D2.3 (I/O2), D2.4 (I/O2), J12.A6 (D+), J12.B6 (D+), U1.71 (PA12)
/Connectors/D-: D2.1 (I/O1), D2.6 (I/O1), J12.A7 (D-), J12.B7 (D-), U1.70 (PA11)
/Connectors/EXT_TEMP1: C53.1, J7.2, R21.1, U1.15 (PC0)
/Connectors/EXT_TEMP2: C52.1, J7.3, R11.1, U1.16 (PC1)
/Connectors/FANN: C93.2, D3.2 (A), J8.2, Q7.1 (D)
/Connectors/FAN_GATE: Q7.2 (G), Q8.1 (D), R40.2
/Connectors/FAN_GATE_B: Q8.2 (G), R42.1, R43.1
/Connectors/FAN_PWM: R43.2, U1.63 (PC6)
/Connectors/HALL1: C19.1, R34.2, U1.7 (PC13)
/Connectors/HALL2: C61.1, R35.2, U1.8 (PC14)
/Connectors/HALL3: C62.1, R36.2, U1.9 (PC15)
/Connectors/HALL_IN1: J10.3, R29.2, R34.1
/Connectors/HALL_IN2: J10.4, R31.2, R35.1
/Connectors/HALL_IN3: J10.5, R33.2, R36.1
/Connectors/MOTOR_TEMP: C60.1, J10.2, U1.18 (PC3_C)
/Connectors/NRST: C55.1, J6.12, SW1.2, U1.14 (NRST)
/Connectors/SERVO: R39.2, U1.59 (PD12)
/Connectors/SERVO_IN: J14.1, R39.1
/Connectors/SPI3_MISO_I2C5_SCL: J9.7, U1.79 (PC11)
/Connectors/SPI3_MOSI_I2C5_SMBA: J9.6, U1.80 (PC12)
/Connectors/SPI3_NSS: J9.5, U1.77 (PA15(JTDI))
/Connectors/SPI3_SCK_I2C5_SDA: J9.4, U1.78 (PC10)
/Connectors/SWCLK: J6.6, U1.76 (PA14(JTCK))
/Connectors/SWDIO: J6.4, U1.72 (PA13(JTMS))
/Connectors/SWO: J6.8, U1.89 (PB3(JTDO))
/Connectors/USBCC1: J12.A5 (CC1), R38.1
/Connectors/USBCC2: J12.B5 (CC2), R37.1
/Connectors/VCP_RX: J6.13, U1.82 (PD1)
/Connectors/VCP_TX: J6.14, U1.81 (PD0)
/HalfBridgeU/GATE+: U1.43 (PE13), U5.B4 (HI)
/HalfBridgeU/GATE-: U1.42 (PE12), U5.A4 (LI)
/HalfBridgeU/HB: C21.1, U5.D3 (HB)
/HalfBridgeU/HIGH_GATE: Q1.1 (G), R8.2, R13.1, R44.2
/HalfBridgeU/HOH: R8.1, U5.D2 (HOH)
/HalfBridgeU/HOL: R44.1, U5.D1 (HOL)
/HalfBridgeU/HS: C21.2, Q1.3 (S1), Q1.5 (S2), Q1.6 (S3), Q2.2 (D2), Q2.4 (D1), R10.1, R13.2, U4.2 (IP-), U5.C1 (HS), U5.D4 (HS), U_HB_PAD.1
/HalfBridgeU/I_CURR_SENS+: C25.1, U1.34 (PB0), U4.4 (VREF)
/HalfBridgeU/I_CURR_SENS-: C28.1, U1.35 (PB1), U4.5 (VOUT)
/HalfBridgeU/LOH: R9.1, U5.B1 (LOH)
/HalfBridgeU/LOL: R47.1, U5.A1 (LOL)
/HalfBridgeU/LOW_GATE: Q2.1 (G), R9.2, R18.1, R47.2
/HalfBridgeU/PHASE: J3.1, U4.1 (IP+), U_HB_PAD.2
/HalfBridgeU/U_PHASE_SENS: R19.2, U1.24 (PA2)
/HalfBridgeV/GATE+: U1.41 (PE11), U8.B4 (HI)
/HalfBridgeV/GATE-: U1.40 (PE10), U8.A4 (LI)
/HalfBridgeV/HB: C34.1, U8.D3 (HB)
/HalfBridgeV/HIGH_GATE: Q3.1 (G), R14.1, R15.2, R45.2
/HalfBridgeV/HOH: R15.1, U8.D2 (HOH)
/HalfBridgeV/HOL: R45.1, U8.D1 (HOL)
/HalfBridgeV/HS: C34.2, HB_PAD_U.1, Q3.3 (S1), Q3.5 (S2), Q3.6 (S3), Q4.2 (D2), Q4.4 (D1), R14.2, R20.1, U6.2 (IP-), U8.C1 (HS), U8.D4 (HS)
/HalfBridgeV/I_CURR_SENS+: C26.1, U1.32 (PC4), U6.4 (VREF)
/HalfBridgeV/I_CURR_SENS-: C39.1, U1.33 (PC5), U6.5 (VOUT)
/HalfBridgeV/LOH: R16.1, U8.B1 (LOH)
/HalfBridgeV/LOL: R48.1, U8.A1 (LOL)
/HalfBridgeV/LOW_GATE: Q4.1 (G), R16.2, R24.1, R48.2
/HalfBridgeV/PHASE: HB_PAD_U.2, J4.1, U6.1 (IP+)
/HalfBridgeV/U_PHASE_SENS: R27.2, U1.23 (PA1)
/HalfBridgeW/GATE+: U1.39 (PE9), U12.B4 (HI)
/HalfBridgeW/GATE-: U1.38 (PE8), U12.A4 (LI)
/HalfBridgeW/HB: C51.1, U12.D3 (HB)
/HalfBridgeW/HIGH_GATE: Q5.1 (G), R17.1, R22.2, R46.2
/HalfBridgeW/HOH: R22.1, U12.D2 (HOH)
/HalfBridgeW/HOL: R46.1, U12.D1 (HOL)
/HalfBridgeW/HS: C51.2, Q5.3 (S1), Q5.5 (S2), Q5.6 (S3), Q6.2 (D2), Q6.4 (D1), R17.2, R28.1, U7.2 (IP-), U12.C1 (HS), U12.D4 (HS), V_HB_PAD.1
/HalfBridgeW/I_CURR_SENS+: C33.1, U1.30 (PA6), U7.4 (VREF)
/HalfBridgeW/I_CURR_SENS-: C91.1, U1.31 (PA7), U7.5 (VOUT)
/HalfBridgeW/LOH: R23.1, U12.B1 (LOH)
/HalfBridgeW/LOL: R49.1, U12.A1 (LOL)
/HalfBridgeW/LOW_GATE: Q6.1 (G), R23.2, R25.1, R49.2
/HalfBridgeW/PHASE: J5.1, U7.1 (IP+), V_HB_PAD.2
/HalfBridgeW/U_PHASE_SENS: R32.2, U1.22 (PA0)
/MCU/HSE_IN: C69.1, U1.12 (PH0), X1.1
/MCU/HSE_OUT: C70.1, U1.13 (PH1), X1.3
/MCU/U_DC_SENS: R7.2, U1.17 (PC2_C)
/MCU/VCAP1: C83.1, U1.48 (VCAP)
/MCU/VCAP2: C84.1, U1.73 (VCAP)
/Power/SW_CB: C5.1, U2.6 (CB)
/Power/SW_FB: R1.2, R2.1, U2.1 (FB)
/Power/SW_SMPS: C5.2, L1.1, U2.5 (SW)
ACTIVE: D5.2 (A), U1.91 (PB5)
BOOT0: R41.2, SW2.2, U1.94 (BOOT0)
ERROR: D4.2 (A), U1.83 (PD2)
FDCAN1_RX: U1.95 (PB8), U15.4 (RXD)
FDCAN1_STB: U1.85 (PD4), U15.8 (STB)
FDCAN1_TX: U1.96 (PB9), U15.1 (TXD)
GND: C1.2, C2.2, C3.2, C4.2, C6.2, C7.2, C8.2, C9.2, C10.2, C11.2, C12.2, C13.2, C14.2, C15.2, C16.2, C17.2, C18.2, C19.2, C20.2, C22.2, C23.2, C24.2, C25.2, C26.2, C27.2, C28.2, C29.2, C30.2, C31.2, C32.2, C33.2, C35.2, C36.2, C37.2, C38.2, C39.2, C40.2, C41.2, C42.2, C43.2, C44.2, C45.2, C46.2, C47.2, C48.2, C49.2, C50.2, C52.2, C53.2, C54.2, C55.2, C56.2, C57.2, C58.2, C59.2, C60.2, C61.2, C62.2, C63.2, C64.2, C65.2, C66.2, C67.2, C68.2, C69.2, C70.2, C71.2, C72.2, C73.2, C74.2, C75.2, C76.2, C77.2, C78.2, C79.2, C80.2, C81.2, C82.2, C83.2, C84.2, C85.2, C86.2, C87.2, C88.2, C89.2, C90.2, C91.2, C94.2, C95.2, D2.2 (GND), J1.N (NEG), J2.N (NEG), J6.5, J6.7, J6.11, J9.3, J10.6, J11.4, J12.A1 (GND), J12.A12 (GND), J12.B1 (GND), J12.B12 (GND), J12.S1 (SHIELD), J14.3, MH1.1, MH2.1, MH3.1, MH4.1, MH5.1, MH6.1, MH7.1, MH8.1, MH9.1, Q2.3 (S1), Q2.5 (S2), Q2.6 (S3), Q4.3 (S1), Q4.5 (S2), Q4.6 (S3), Q6.3 (S1), Q6.5 (S2), Q6.6 (S3), Q7.3 (S), Q8.3 (S), R2.2, R3.2, R5.2, R11.2, R12.2, R18.2, R21.2, R24.2, R25.2, R26.2, R30.2, R37.2, R38.2, R41.1, R42.2, R58.2, R59.2, R60.2, SW1.1, SW3.1, SW4.1, U1.10 (VSS), U1.19 (VSSA), U1.26 (VSS), U1.49 (VSS), U1.74 (VSS), U1.99 (VSS), U2.4 (GND), U3.1 (ADJ), U4.3 (GND), U5.A2 (VSS), U6.3 (GND), U7.3 (GND), U8.A2 (VSS), U12.A2 (VSS), U13.6 (GNDIO), U13.7 (GND), U14.5 (TEST), U14.13 (GND), U15.2 (GND), X1.2 (G), X1.4 (G)
IMU_INT1: U1.97 (PE0), U13.4 (INT1)
IMU_INT2: U1.93 (PB7), U13.9 (INT2)
unnamed: C18.1, R4.2, R5.1, R7.1
unnamed: C36.1, R10.2, R12.1, R19.1
unnamed: C85.1, R20.2, R26.1, R27.1
unnamed: C87.1, R28.2, R30.1, R32.1
unnamed: C94.1, R56.2
unnamed: C95.1, R57.2
unnamed: D1.1 (K), R3.1
unnamed: D4.1 (K), R58.1
unnamed: D5.1 (K), R59.1
unnamed: D6.1 (K), R60.1
SPI2_MISO: U1.53 (PB14), U14.3 (MISO)
SPI2_MOSI: U1.54 (PB15), U14.4 (MOSI)
SPI2_NSS: U1.51 (PB12), U14.1 (CSn)
SPI2_SCK: U1.52 (PB13), U14.2 (CLK)
SPI4_MISO: U1.4 (PE5), U13.1 (SDO)
SPI4_MOSI: U1.5 (PE6), U13.14 (SDX)
SPI4_NSS: U1.3 (PE4), U13.12 (CSB)
SPI4_SCK: U1.1 (PE2), U13.13 (SCX)
USR_BTN1: R56.1, SW3.2, U1.69 (PA10)
USR_BTN2: R57.1, SW4.2, U1.68 (PA9)
U_DC: C1.1, C2.1, C3.1, C4.1, C11.1, C12.1, C13.1, C14.1, C15.1, C17.1, C27.1, C30.1, C32.1, C35.1, C42.1, C44.1, C45.1, C46.1, C47.1, C49.1, C50.1, C67.1, C68.1, C81.1, C88.1, C90.1, J1.P (POS), J2.P (POS), Q1.2 (D2), Q1.4 (D1), Q3.2 (D2), Q3.4 (D1), Q5.2 (D2), Q5.4 (D1), R4.1, U2.2 (EN), U2.3 (VIN)

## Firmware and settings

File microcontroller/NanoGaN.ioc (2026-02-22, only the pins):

Mcu.UserName=STM32H723VGTx
PA0.GPIO_Label=U_PHASE_SENS_W
PA0.Signal=ADC1_INP16
PA1.GPIO_Label=U_PHASE_SENS_V
PA1.Signal=ADC1_INP17
PA11.Signal=USB_OTG_HS_DM
PA12.Signal=USB_OTG_HS_DP
PA13(JTMS/SWDIO).Signal=DEBUG_JTMS-SWDIO
PA14(JTCK/SWCLK).Signal=DEBUG_JTCK-SWCLK
PA15(JTDI).Signal=SPI3_NSS
PA2.GPIO_Label=U_PHASE_SENS_U
PA2.Signal=ADCx_INP14
PA4.Signal=COMP_DAC11_group
PA5.Signal=COMP_DAC12_group
PA6.Signal=ADCx_INP3
PA7.Signal=ADCx_INN3
PB0.Signal=ADCx_INN5
PB1.Signal=ADCx_INP5
PB12.Signal=SPI2_NSS
PB13.Signal=SPI2_SCK
PB14.Signal=SPI2_MISO
PB15.Signal=SPI2_MOSI
PB3(JTDO/TRACESWO).Signal=DEBUG_JTDO-SWO
PB5.GPIO_Label=ACTIVE
PB5.Signal=GPIO_Output
PB7.GPIO_Label=IMU_INT2
PB7.Signal=GPIO_Input
PB8.Signal=FDCAN1_RX
PB9.Signal=FDCAN1_TX
PC0.Signal=ADCx_INP10
PC1.Signal=ADCx_INP11
PC10.Signal=SPI3_SCK
PC11.Signal=SPI3_MISO
PC12.Signal=SPI3_MOSI
PC13.GPIO_Label=HALL1
PC13.Signal=GPIO_Input
PC14-OSC32_IN.GPIO_Label=HALL2
PC14-OSC32_IN.Signal=GPIO_Input
PC15-OSC32_OUT.GPIO_Label=HALL3
PC15-OSC32_OUT.Signal=GPIO_Input
PC2_C.Signal=ADC3_INP0
PC3_C.Signal=ADC3_INP1
PC4.Signal=ADCx_INP4
PC5.Signal=ADCx_INN4
PC6.GPIO_Label=FAN_PWM
PC6.Signal=S_TIM3_CH1
PD0.Signal=UART4_RX
PD1.Signal=UART4_TX
PD2.GPIO_Label=ERROR
PD2.Signal=GPIO_Output
PD4.GPIO_Label=FDCAN1_STB
PD4.Signal=GPIO_Output
PD5.Signal=USART2_TX
PD6.Signal=USART2_RX
PD7.Signal=USART2_CK
PE0.GPIO_Label=IMU_INT1
PE0.Signal=GPIO_Input
PE10.GPIO_Label=GATE_V_L
PE10.Signal=TIM1_CH2N
PE11.GPIO_Label=GATE_V_H
PE11.Signal=S_TIM1_CH2
PE12.GPIO_Label=GATE_U_L
PE12.Signal=TIM1_CH3N
PE13.GPIO_Label=GATE_U_H
PE13.Signal=S_TIM1_CH3
PE2.Signal=SPI4_SCK
PE4.Signal=SPI4_NSS
PE5.Signal=SPI4_MISO
PE6.Signal=SPI4_MOSI
PE8.GPIO_Label=GATE_W_L
PE8.Signal=TIM1_CH1N
PE9.GPIO_Label=GATE_W_H
PE9.Signal=S_TIM1_CH1
PH0-OSC_IN.Signal=RCC_OSC_IN
PH1-OSC_OUT.Signal=RCC_OSC_OUT

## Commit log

2026-01-17 Initial commit. First draft of the schematic. WiP PCB.
    [BMI323_BOS.step, D0008A.stp, DCK0005A.stp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]
2026-01-18 Analog current filters were removed, some footprints were fixed and initial rough layout has been made.
    [LMG1205YFXR.stp, NanoGaN.kicad_pcb, NanoGaN.kicad_sch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]
2026-01-19 Updated the DC/DC converter from I_out = 2A to 3.5A and fsw = 1.1MHz to 400kHz
    [Coilcraft-XAL6060.step, NanoGaN.kicad_pcb, XAL4030-332MEC.stp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]
2026-01-21 pdf export and small fixes
    [NanoGaN.kicad_sch, half_bridge.kicad_sch, mcu.kicad_sch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]
2026-01-23 added fan connector
    [connectors.kicad_sch]
2026-01-23 Added PWM fan control
    [NanoGaN.kicad_sch, connectors.kicad_sch, mcu.kicad_sch]
2026-01-24 added cooling channel trace on F silkscreen and rearranged a few components
    [NanoGaN.kicad_pcb]
2026-01-24 Differential pair naming added. Duplicate footprint problem fixed.
    [NanoGaN.kicad_pcb, connectors.kicad_sch, half_bridge.kicad_sch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]
2026-01-24 added Net Classes added +5V supply selection header
    [NanoGaN.kicad_pcb, connectors.kicad_sch, half_bridge.kicad_sch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]
2026-01-25 WiP layout
    [NanoGaN.kicad_pcb, NanoGaN.kicad_sch, connectors.kicad_sch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]
2026-01-25 added over current protection triggers (adjustable)
    [NanoGaN.kicad_pcb, NanoGaN.kicad_sch, UDFN8_1P6X1P6_ONS.step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]
2026-01-26 added calculation for schmitt trigger
    [schmitt_trigger.ods]
2026-01-26 added step file of cooling channel and modified the layout
    [NanoGaN.kicad_pcb, cc_v3.step]
2026-01-27 added cooling channel symbol, footprint and 3D model
    [NanoGaN.kicad_pcb, power.kicad_sch]
2026-01-28 added the first draft of the layout
    [ACS37030LLZATR-065B3.stp, EMHS800GRA241MKG5S.stp, NanoGaN.kicad_pcb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]
2026-01-28 added heatsinks and updated cooling channel
    [HSB01-080808.step, NanoGaN.kicad_pcb, NanoGaN.kicad_sch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]
2026-02-02 small footprint update for cooling channel and heatsinks
    [NanoGaN.kicad_pcb]
2026-02-02 new version of heatsink, channel and mounting holes
    [ICK_S.step, NanoGaN.kicad_pcb, NanoGaN.kicad_sch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]
2026-02-04 wip layout (power)
    [NanoGaN.kicad_pcb]
2026-02-07 placed a few back side components
    [NanoGaN.kicad_pcb]
2026-02-10 cooling once again
    [NanoGaN.kicad_pcb, cc_v5.step]
2026-02-13 first draft of the PCB
    [NanoGaN.kicad_pcb, NanoGaN.kicad_sch, connectors.kicad_sch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]
2026-02-14 gate signals moved from front layer to inner layers to make space for dc connections.
    [NanoGaN.kicad_pcb]
2026-02-14 wip second draft of the PCB
    [NanoGaN.kicad_pcb, connectors.kicad_sch, half_bridge.kicad_sch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]
2026-02-16 third draft of the PCB
    [NanoGaN.kicad_pcb, mcu.kicad_sch]
2026-02-16 couple of ERC fixes
    [NanoGaN.kicad_pcb, NanoGaN.kicad_sch, connectors.kicad_sch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]
2026-02-16 cooling v6
    [NanoGaN.kicad_pcb, cc_v6.step]
2026-02-17 ERC errors have been fixed. XTAL changed to 12MHz. WiP DRC errors.
    [NanoGaN.kicad_pcb, NanoGaN.kicad_sch, connectors.kicad_sch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]
2026-02-17 fixed all ERC and DRC errors/warnings, now in review stage.
    [NanoGaN.kicad_pcb, NanoGaN.kicad_sch, connectors.kicad_sch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]
2026-02-17 exported the pdfs
    [NanoGaN.kicad_pcb]
2026-02-18 changed the VREF capacitance (ACS37030) to 100pF
    [NanoGaN.kicad_pcb, half_bridge.kicad_sch]
2026-02-19 added leds and buttons
    [NanoGaN.kicad_pcb, NanoGaN.kicad_sch, connectors.kicad_sch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]
2026-02-20 various silk screen changes
    [NanoGaN.kicad_sch, cc_v3.step, cc_v4.step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]
2026-02-22 schematic and PCB reviews are done, ready for release and first order.
    [InterruptAssignmentTable.csv, NanoGaN.kicad_sch, bom.csv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]
2026-02-24 changed the IMU from BMI323 to LSM6DSVTR
    [LGA14-L_2P59X3P1X0P5_STM.step, bom.csv, designators.csv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]
2026-02-24 wip gate driver change
    [1EDN7136UXTSA1.stp, BMI323_BOS.step, half_bridge.kicad_sch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]
2026-03-08 gate driver change is complete
    [NanoGaN.kicad_sch, bom.csv, designators.csv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]
2026-03-09 small order changes and ESD warning symbol
    [bom.csv, designators.csv, half_bridge.kicad_sch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]
2026-05-27 Added picture from the real board and one measurement

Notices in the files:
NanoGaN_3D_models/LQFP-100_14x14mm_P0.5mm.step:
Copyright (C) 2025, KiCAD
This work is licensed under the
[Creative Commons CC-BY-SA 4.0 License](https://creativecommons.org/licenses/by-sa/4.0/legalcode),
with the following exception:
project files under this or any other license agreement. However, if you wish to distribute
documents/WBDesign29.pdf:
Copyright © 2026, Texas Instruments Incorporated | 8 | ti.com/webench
